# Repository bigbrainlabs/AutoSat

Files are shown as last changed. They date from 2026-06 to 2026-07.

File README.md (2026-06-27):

# AutoSat

Automatische Satelliten-Ausrichtung mit Echtzeit-Tracking für kleine Flachantennen/Schüsseln (35–40 cm) – hält den Satelliten auch während der Fahrt im Fokus. Für Boote, Wohnmobile, Caravans.

**Ziel:** DIY statt teure kommerzielle Systeme. Selbstgemacht ist wissen was drin ist und bezahlbar.

> Status: 🔧 Prototyp in Betrieb – Feinabstimmung läuft

---

## Konzept

Astra 19.2°E ist geostationär – steht fest am Himmel. Bewegt sich das Boot (dreht, schaukelt), muss die Schüssel nachgeführt werden – aktiv, auch während der Fahrt.

Die Plattform dreht sich auf einer Drehachse (Azimut), ein Servo kippt die Schüssel (Elevation). Ein IMU mit Kompass und Gyroskop misst die aktuelle Ausrichtung; die Firmware berechnet daraus den Fehler und korrigiert ihn.

**Tracking-Ansatz:** absolutes Azimut-Tracking über Kompassheading. Die Plattform wird einmalig nach Süden ausgerichtet (Kalibrierung), danach kennt das System jederzeit die absolute Schüsselrichtung:

```
Schüsselrichtung = Kompass-Heading + Motorposition + Montageoffset
Fehler = Ziel-Azimut − Schüsselrichtung
```

Elevation wird einmalig kalibriert (Servo-Winkel bei Satellitensignal gespeichert) und im Tracking per IMU-Achse für Boots-Neigung korrigiert.

---

## Hardware (aktueller Aufbau)

| # | Komponente | Funktion | Link |
|---|---|---|---|
| 1 | ESP32-C3 SuperMini | Steuerung, WiFi Access Point | [Amazon](https://amzn.to/4w9G6VN) |
| 2 | GY-91 (MPU-6500 + BMP280) | Gyroskop + Beschleunigung (Pitch/Roll/Yaw) | [Amazon](https://amzn.to/4wfitv6) |
| 3 | GY-271 (HMC5883L) | Magnetometer / Kompass | [Amazon](https://amzn.to/3QKusSe) |
| 4 | TMC2209 Schrittmotortreiber | Azimut-Motor, UART-Ansteuerung, StealthChop | [Amazon](https://amzn.to/3SqNw8E) |
| 5 | NEMA17 Schrittmotor | Azimut-Antrieb, Zahnradübersetzung 2:1 | [Amazon](https://amzn.to/4g7nUHM) |
| 6 | MG996R Servo | Elevation-Antrieb | [Amazon](https://amzn.to/4w8z7MJ) |
| 7 | GT2-Riemen + Umlenkrolle | Kraftübertragung Azimut-Antrieb | [Amazon](https://amzn.to/4oPDdqM) |
| 9 | Drehlager für Plattform | Zentrale Drehachse | [Amazon](https://amzn.to/4oMyjL0) |
| 10 | Schleifring 6-polig | Strom- & Signalübertragung über die Drehachse (verhindert Kabelwicklung) | [Amazon](https://amzn.to/4eMYXz2) |
| 11 | DC-DC Konverter 12V → 5V | Bordnetz-Versorgung für Servo und ESP32 | [Amazon](https://amzn.to/4oSf8zE) |

> Spannungsversorgung und Kleinmaterial (Kabel, Stecker, Dupont) nach eigenem Bedarf.

### Pin-Belegung

| Pin | Funktion |
|---|---|
| GPIO2 | STEP (TMC2209) |
| GPIO4 | DIR (hardwärts verkabelt, ungenutzt – Richtung via UART) |
| GPIO5 | Servo (MG996R, PWM) |
| GPIO6 | I2C SDA (MPU-6500, HMC5883L) |
| GPIO7 | I2C SCL |
| GPIO8 | TMC2209 UART TX (= LED-Pin, flackert bei Richtungswechsel) |
| GND | TMC2209 ENABLE (fest LOW = immer aktiv) |

### Wichtige Hardware-Eigenheiten

- **ESP32-C3 ist Single-Core (RISC-V):** `noInterrupts()` blockiert auch den WiFi-Stack. Gelöst durch minimale Interrupt-Blackouts (nur Adresse 3 ansprechen, ~8 ms) + `yield()` danach.
- **TMC2209 UART-Adresse = 3:** Bei 1/16-Mikroschritt sind MS1=HIGH, MS2=HIGH → UART-Adresse = 2·MS2+MS1 = 3. Adresse 0 wäre falsch.
- **NEMA17 Resonanzzone:** 80–300 Vollschritte/s → bei 16× Mikroschritt Mindest-Delay 800 µs/Schritt (= 39 Vollschritte/s).
- **Richtungssteuerung per UART:** DIR-Pin wird vom IC ignoriert; Richtung läuft über GCONF.shaft-Bit (Register 0x00).

---

## Software-Architektur

### Firmware (`firmware/firmware.ino` + `firmware/webportal.h`)

**IMU-Filter:**
- Pitch/Roll: Komplementärfilter, α=0.98 (Gyro + Beschleunigungssensor)
- Yaw/Heading: dynamisches α – bei Drehung 0.97 (Gyro dominiert), bei Stillstand 0.85 (Kompass zieht Drift heraus)
- Tilt-kompensiertes Magnetometer-Heading (Pitch/Roll-Korrektur)

**Azimut-Tracking:**
- Absolut: `dishAz = heading_yaw + currentSteps/STEPS_PER_DEGREE + azMountOffset`
- `azMountOffset` wird einmalig bei Süd-Kalibrierung gesetzt und in NVM gespeichert
- Soft-Limits: ±180° × STEPS_PER_DEGREE (nach Kalibrierung dynamisch gesetzt)

**Elevation-Tracking:**
- Referenz-Servo-Winkel (`servoCalAngle`) einmalig kalibriert und in NVM gespeichert
- Korrektur per wählbarer IMU-Achse: +Pitch / +Roll / −Pitch / −Roll (über Portal einstellbar)
- Rampe: manuell 60 ms/° (~16°/s), Live-Tracking 12 ms/° (~83°/s)
- Servo nach Neustart deaktiviert – muss im Portal explizit freigegeben werden

**Wichtige Parameter:**

| Parameter | Wert | Bedeutung |
|---|---|---|
| STEPS_PER_DEGREE | 17,78 | 200 Schritte/U × 16× Mikro × 2:1 Übersetzung |
| STEP_DELAY_TRACK | 300 µs | Tracking-Schrittgeschwindigkeit |
| STEP_MAN_MIN | 800 µs | Minimaler manueller Delay (Resonanz vermeiden) |
| TMC IRUN | 25 % (IRUN=8) | Motorstrom Fahren |
| TMC IHOLD | 6 % (IHOLD=2) | Motorstrom Halten |

---

## Web-Portal

Der ESP32-C3 öffnet einen WiFi Access Point (`AutoSat`). Portal unter `192.168.4.1`.

**Tabs:**

| Tab | Inhalt |
|---|---|
| Status | Tracking starten/stoppen, Süd-Referenz setzen, Azimut-Kalibrierung |
| Elevation | Servo freigeben, manuell positionieren, MIN/MAX setzen, kalibrieren, Achse wählen |
| GPS/Sat | Koordinaten, Satelliten-Längengrad, Azimut/Elevation-Anzeige |
| Motor | Manuelle Azimut-Schritte, Motor-Test, Step-Limits setzen |
| WiFi | WLAN-Client konfigurieren (optional, für MQTT/Internet) |
| Debug | Live-Rohdaten IMU, Heading, Fehlerwinkel, Loop-Hz |

---

## Kalibrierung (Erstinbetriebnahme)

### 1. Azimut – Süd-Referenz setzen

1. Plattform physisch nach Süden drehen (Kompass-App oder Markierung)
2. Portal → Status → **„Süd-Referenz setzen"**
3. Firmware setzt: `currentSteps = 0`, Soft-Limits ±180°, `azMountOffset` aus aktuellem Kompasswert
4. Einmalig – wird in NVM gespeichert, gilt für alle Neustarts

### 2. Elevation – Servo kalibrieren

1. Portal → Elevation → **„Servo aktivieren"** (Servo fährt auf gespeicherte Position)
2. Servo manuell mit ±1°/±10°-Buttons auf Satellitensignal ausrichten
3. Portal → Elevation → **„Kalibrieren & speichern"**
4. Dieser Servo-Winkel wird als Referenz gespeichert

### 3. Elevation-Korrekturachse wählen

1. Tracking starten
2. Boot seitlich kippen → Schüssel muss in die richtige Richtung nachkorrigieren
3. Falls falsch: Portal → Elevation → anderen Achsen-Button (+Pitch / +Roll / −Pitch / −Roll) probieren

### 4. Tracking starten

1. Portal → Status → **„Tracking starten"** (kalibriert Gyro-Offset für ~2,5 s)
2. System hält Astra 19.2°E automatisch im Fokus

---

## Ablauf nach jedem Neustart

1. ESP32 startet, WiFi-AP `AutoSat` verfügbar
2. Servo ist **deaktiviert** – keine automatische Bewegung
3. Portal öffnen → Elevation → **„Servo aktivieren"** → Servo fährt auf kalibrierten Winkel
4. Portal → Status → **„Tracking starten"**

Azimut-Motor startet sofort an der gespeicherten Step-Position aus dem letzten Betrieb (NVM).

---

## Repo-Struktur

```
AutoSat/
├── README.md
├── firmware/
│   ├── firmware.ino               ← Haupt-Firmware (IMU, Motor, Tracking, NVM)
│   └── webportal.h                ← Web-Portal (HTML/CSS/JS + HTTP-Handler)
├── docs/
│   ├── bedienung-webportal.md     ← Bedienung & Kalibrierung über das Web-Portal
│   └── schaltplan.md              ← Schaltplan & Verdrahtung aller Komponenten
└── 3D-Print-Parts/
    ├── Autosat-Elevation_Mount.stl  ← Halterung Elevation-Servo
    └── Nema17-Ground_Mount.stl      ← Grundhalterung NEMA17 Azimut-Motor
```

**Dokumentation:**
- [Bedienung & Kalibrierung über das Web-Portal](docs/bedienung-webportal.md)
- [Schaltplan & Verdrahtung](docs/schaltplan.md)

---

## NVM-Schlüssel (Preferences, Namespace "autosat")

| Schlüssel | Typ | Bedeutung |
|---|---|---|
| `steps` | Long | Letzte Motor-Position |
| `azMntOff` | Float | Azimut-Montageoffset (Süd-Kalibrierung) |
| `azMin` / `azMax` | Long | Azimut Soft-Limits in Steps |
| `srvCalAng` | Int | Kalibrierter Servo-Winkel (Elevation) |
| `servoMin` / `servoMax` | Int | Servo-Endpunkte |
| `elvAxis` | Int | Korrektur-Achse (0=+Pitch, 1=+Roll, 2=−Pitch, 3=−Roll) |
| `gpsLat` / `gpsLon` | Double | GPS-Koordinaten |
| `satLon` | Float | Satelliten-Längengrad (Default: 19.2) |
| `azOffset` | Float | Azimut-Offset für Satellitenberechnung |
| `azMountOffset` | Float | (identisch mit azMntOff, älterer Schlüssel) |

---

## Offene Punkte

- [ ] Genauigkeit bei längerem Betrieb auf dem Wasser testen
- [ ] Kompass-Kalibrierung (Hard/Soft-Iron) implementieren
- [ ] Achsen-Transformation (cos/sin) bei bekannter Board-Montage aktivieren
- [ ] MQTT-Integration (optional)
- [ ] Gehäuse / wetterfeste Montage

---

---

## Projekt unterstützen

Wer das Projekt gut findet – ich schreibe die Buch-Serie **„Logbuch ohne Pose"** über das Leben auf dem Boot, ehrlich und ungeschönt. In **Band 7** wird AutoSat eine Rolle spielen.

👉 [Logbuch ohne Pose – bei Amazon](https://amzn.to/4w6gBo9)

Mit dem Kauf eines Bandes oder der ganzen Serie unterstützt du die Weiterentwicklung direkt. Danke! ⚓

---

## Lizenz

Dieses Projekt steht unter der **GNU General Public License v3.0 (GPL-3.0)**.

Das bedeutet: Du kannst den Code frei verwenden, verändern und weitergeben – solange Ableitungen ebenfalls unter der GPL v3 veröffentlicht werden und die Quelle angegeben wird.

Weitere Details: [https://www.gnu.org/licenses/gpl-3.0.html](https://www.gnu.org/licenses/gpl-3.0.html)

---

*"~50 € DIY. ~3.000 € kommerziell. Der Rest ist Physik."* ⚓

🐾 Buster ist nach wie vor skeptisch.

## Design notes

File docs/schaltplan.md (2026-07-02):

# AutoSat – Schaltplan & Verdrahtung

> **Grafischer Schaltplan:** [Fritzing/autosat_v1.fzz](../Fritzing/autosat_v1.fzz)

## Systemübersicht

```
                        ┌──────────────────────────┐
                        │     ESP32-C3 SuperMini    │
                        │                          │
          3,3V ────────►│ 3V3              GPIO2   ├──── STEP ────────────► TMC2209
           GND ────────►│ GND              GPIO4   ├──── DIR  ────────────► TMC2209 (per UART übersteuert)
                        │                  GPIO5   ├──── PWM  ────────────► MG996R Servo (Signal)
                        │                  GPIO6   ├──── SDA  ─────┬──────► GY-91 (MPU-6500)
                        │                  GPIO7   ├──── SCL  ─────┴──────► GY-271 (HMC5883L)
                        │                  GPIO8   ├──── UART TX ─────────► TMC2209 PDN_UART
                        └──────────────────────────┘
```

---

## Stromversorgung

```
Bordnetz 12 V
    │
    ├──► TMC2209  VM  (12 V Motorspannung)
    │
    └──► DC-DC Konverter 12 V → 5 V
              │
              ├──► MG996R Servo  VCC (5 V)
              │
              └──► ESP32-C3  5V-Pin (nicht USB – direkt auf 5V-Rail)
                        │
                        └── 3,3 V intern (für GY-91, GY-271, TMC2209 VIO)
```

> Den ESP32-C3 am 5V-Pin (nicht USB-C) anschließen, wenn der DC-DC Konverter die Versorgung übernimmt. Nie gleichzeitig USB und externen 5V anlegen.

---

## ESP32-C3 SuperMini – Pin-Belegung

| GPIO | Funktion | Ziel |
|---|---|---|
| GPIO2 | STEP (Digital Out) | TMC2209 STEP |
| GPIO4 | DIR (Digital Out, ungenutzt) | TMC2209 DIR |
| GPIO5 | PWM (Servo) | MG996R Signal-Kabel |
| GPIO6 | I2C SDA | GY-91 SDA + GY-271 SDA |
| GPIO7 | I2C SCL | GY-91 SCL + GY-271 SCL |
| GPIO8 | UART TX (Software Serial) | TMC2209 PDN_UART |
| GND | Masse | Alle Komponenten |
| 3V3 | 3,3-V-Ausgang | GY-91 VCC, GY-271 VCC, TMC2209 VIO |

---

## TMC2209 Schrittmotortreiber

```
ESP32-C3 GPIO2  ──────────────────────► STEP
ESP32-C3 GPIO4  ──────────────────────► DIR
ESP32-C3 GPIO8  ──── 1 kΩ ────────────► PDN_UART  ◄──── 100 kΩ Pull-up ── 3,3 V
ESP32-C3 GND    ──────────────────────► EN   (fest LOW = immer aktiv)
ESP32-C3 3V3    ──────────────────────► VIO
Bordnetz 12 V   ──────────────────────► VM
GND             ──────────────────────► GND

MS1             ──────────────────────► 3,3 V   (HIGH)
MS2             ──────────────────────► 3,3 V   (HIGH)
                                       → UART-Adresse 3 (2×MS2 + MS1 = 2×1 + 1 = 3)

NEMA17 Spule A  ──────────────────────► 1A / 1B
NEMA17 Spule B  ──────────────────────► 2A / 2B
```

**PDN_UART-Beschaltung (Single-Wire UART):**

```
ESP32 GPIO8 ──┬── 1 kΩ ──► PDN_UART
              │
            (optional: 100 kΩ Pull-up nach 3,3 V direkt am PDN_UART-Pin)
```

> Richtungssteuerung läuft ausschließlich per UART (GCONF.shaft-Bit, Register 0x00). Der DIR-Pin wird vom IC ignoriert.

---

## GY-91 (MPU-6500 + BMP280) – Gyroskop & Beschleunigung

| GY-91 Pin | ESP32-C3 Pin |
|---|---|
| VCC | 3V3 |
| GND | GND |
| SDA | GPIO6 |
| SCL | GPIO7 |

> I2C-Adresse MPU-6500: **0x68** (AD0 auf GND)

---

## GY-271 (HMC5883L) – Magnetometer / Kompass

| GY-271 Pin | ESP32-C3 Pin |
|---|---|
| VCC | 3V3 |
| GND | GND |
| SDA | GPIO6 (gemeinsamer I2C-Bus mit GY-91) |
| SCL | GPIO7 (gemeinsamer I2C-Bus mit GY-91) |

> I2C-Adresse HMC5883L: **0x1E** (fest)

### I2C-Bus Pull-ups

Beide Sensoren hängen am selben I2C-Bus. Falls keine Pull-ups auf den Modulen vorhanden sind (GY-91 und GY-271 haben sie meist onboard):

```
SDA ──── 4,7 kΩ ──── 3,3 V
SCL ──── 4,7 kΩ ──── 3,3 V
```

---

## MG996R Servo – Elevation-Antrieb

| Servo-Kabel | Anschluss |
|---|---|
| Signal (Orange/Gelb) | ESP32-C3 GPIO5 |
| VCC (Rot) | DC-DC Konverter 5 V |
| GND (Braun/Schwarz) | GND (gemeinsam mit ESP32) |

> Der Servo sitzt auf der rotierenden Plattform – Signal, VCC und GND werden über den 6-poligen Schleifring in der Drehachse geführt.

---

## NEMA17 Schrittmotor – Azimut-Antrieb

Die vier Motorleitungen werden an den TMC2209 angeschlossen. Typische Farbbelegung (je nach Hersteller prüfen!):

| Motorleitung | TMC2209 Pin | Typische Farbe |
|---|---|---|
| Spule A+ | 1A | Schwarz |
| Spule A− | 1B | Grün |
| Spule B+ | 2A | Rot |
| Spule B− | 2B | Blau |

> Spulenpaare mit Multimeter messen: beide Enden einer Spule zeigen Widerstand (~1–5 Ω). Kreuzpaarung dreht den Motor rückwärts – einfach ein Spulenpaar umpolen.

---

## Häufige Fehler

- **GND nicht gemeinsam:** Alle Komponenten müssen auf dem selben GND-Potential liegen. Servo-GND unbedingt mit ESP32-GND verbinden, sonst fehlerhaftes PWM-Signal.
- **TMC2209 UART-Adresse falsch:** MS1 und MS2 müssen beide HIGH (3,3 V) sein → Adresse 3. Adresse 0 (beide LOW) führt zu keiner Kommunikation.
- **Magnetometer zu nah am Motor:** HMC5883L muss möglichst weit weg von NEMA17 und den Motorstromkabeln montiert sein – starke Störfelder verfälschen den Kompasswert.
- **Servo direkt an 3,3 V:** Führt zu Brownouts des ESP32. Immer externe 5-V-Versorgung (DC-DC Konverter) verwenden.

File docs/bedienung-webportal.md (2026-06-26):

# AutoSat – Bedienung & Kalibrierung über das Web-Portal

## Verbindung herstellen

1. ESP32-C3 einschalten (USB oder Bordstrom)
2. Mit dem WLAN-Netz **AutoSat** verbinden (kein Passwort)
3. Browser öffnen → `192.168.4.1`

---

## Tabs im Überblick

| Tab | Funktion |
|---|---|
| **Status** | Tracking starten/stoppen, Süd-Referenz setzen |
| **Elevation** | Servo steuern, Elevation kalibrieren, Korrekturachse wählen |
| **GPS/Sat** | GPS-Koordinaten eingeben, Satelliten-Längengrad festlegen |
| **Motor** | Manuelle Azimut-Schritte, Step-Limits setzen |
| **WiFi** | Optionaler WLAN-Client für MQTT/Internet |
| **Debug** | Live-Rohdaten: IMU, Heading, Fehlerwinkel, Loop-Hz |

---

## Erstinbetriebnahme (einmalig)

### Schritt 1 – GPS-Koordinaten eingeben

Tab **GPS/Sat** → eigene Breite/Länge eintragen → **Speichern**.  
Der Satellit (Standard: Astra 19.2°E) wird automatisch berechnet.

### Schritt 2 – Azimut-Südkalibrierung

1. Plattform physisch nach **Süden** drehen (Kompass-App oder Markierung am Gerät)
2. Tab **Status** → **„Süd-Referenz setzen"**
3. Das System setzt `currentSteps = 0`, berechnet den Montageoffset aus dem aktuellen Kompasswert und speichert alles dauerhaft im NVM

> Diese Kalibrierung gilt für alle Neustarts. Nur wiederholen, wenn die Plattform physisch umgebaut wurde.

### Schritt 3 – Elevation-Servo kalibrieren

1. Tab **Elevation** → **„Servo aktivieren"**  
   Der Servo fährt auf den zuletzt gespeicherten Winkel.
2. Mit **+1° / −1°** (Feinabstimmung) oder **+10° / −10°** (grob) auf Satellitensignal ausrichten  
   → Empfang prüfen am TV oder Receiver (maximale Signalstärke)
3. **„Kalibrieren & speichern"** – dieser Servo-Winkel ist jetzt die Referenz für den Tracking-Betrieb

### Schritt 4 – Korrekturachse wählen

1. Tab **Status** → **„Tracking starten"**
2. Boot seitlich kippen – die Schüssel muss aktiv gegensteuern
3. Falls sie in die falsche Richtung korrigiert:  
   Tab **Elevation** → anderen Achsen-Button wählen: **+Pitch / −Pitch / +Roll / −Roll**
4. Solange wechseln, bis die Korrektur stimmt

---

## Normaler Betrieb (nach jedem Neustart)

1. Mit WLAN **AutoSat** verbinden, Portal öffnen
2. Tab **Elevation** → **„Servo aktivieren"**  
   (Servo ist nach Neustart deaktiviert – Sicherheitsmaßnahme)
3. Tab **Status** → **„Tracking starten"**  
   Das System kalibriert den Gyro-Offset für ca. 2,5 Sekunden, dann läuft das Tracking automatisch

> Der Azimut-Motor startet sofort an der gespeicherten Step-Position aus dem letzten Betrieb.

---

## Tracking manuell stoppen

Tab **Status** → **„Tracking stoppen"**  
Servo und Motor bleiben in ihrer aktuellen Position, reagieren aber nicht mehr auf Bewegungen.

---

## Motor manuell bewegen (Tab: Motor)

- **Schritte +/−**: Azimut manuell in Schritten verfahren (zum Testen oder Ausrichten)
- **Step-Limits setzen**: Soft-Limits für den Azimut-Bereich definieren (verhindert Kabelwicklung)
- **Motor-Test**: Kurzer Testlauf, um Motorstrom und Verbindung zu prüfen

---

## Debug-Tab – was bedeutet was?

| Wert | Bedeutung |
|---|---|
| **Heading** | Berechnetes Kompass-Heading (tilt-kompensiert), 0°=Nord |
| **Pitch / Roll** | Neigung des Boards in Grad |
| **dishAz** | Aktuelle berechnete Schüsselrichtung (absolut) |
| **Fehlerwinkel** | Differenz Ziel-Azimut − dishAz (was der Motor korrigieren muss) |
| **Loop-Hz** | Verarbeitungsgeschwindigkeit der Firmware-Hauptschleife |

---

## Häufige Probleme

**Tracking dreht in die falsche Richtung (Azimut)**  
→ Süd-Kalibrierung wiederholen. Plattform muss beim Setzen der Referenz exakt nach Süden zeigen.

**Elevation korrigiert falsch bei Schaukeln**  
→ Korrekturachse wechseln (Tab Elevation, +Pitch/−Pitch/+Roll/−Roll).

**Servo reagiert nicht**  
→ Servo nach jedem Neustart erst über „Servo aktivieren" freigeben.

**Kompass dreht beim Betrieb der Motoren**  
→ Magnetometer (GY-271) so weit wie möglich von Schrittmotor und Stromkabeln entfernt montieren.

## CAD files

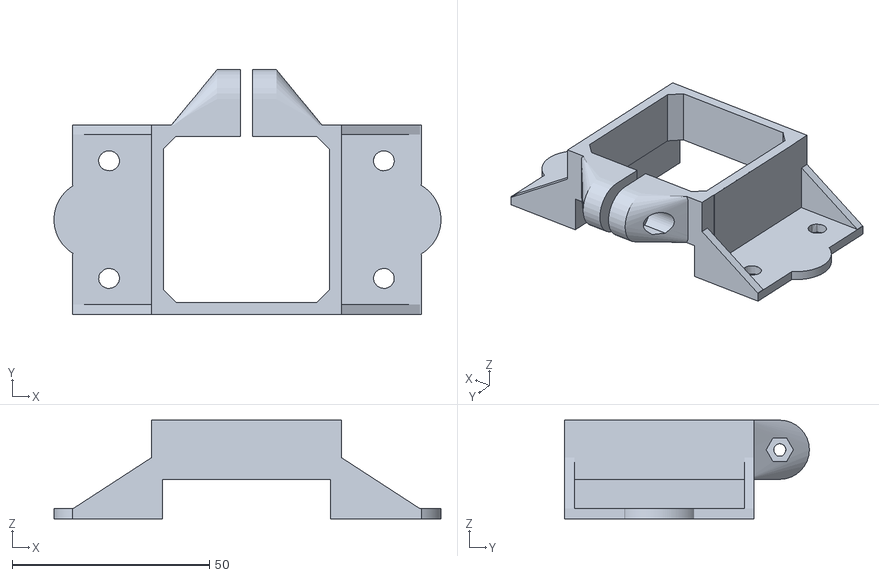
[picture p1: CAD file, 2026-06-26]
3D-Print-Parts/Nema17-Ground_Mount.stl
98.0 x 62.0 x 25.0

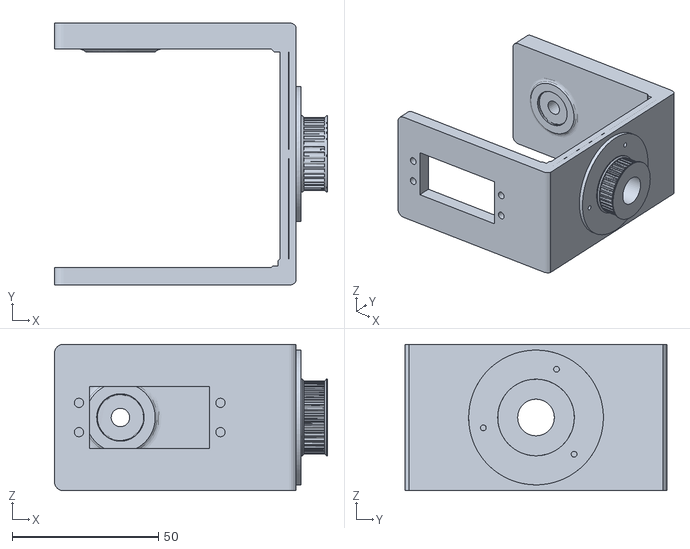
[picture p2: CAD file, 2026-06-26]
3D-Print-Parts/Autosat-Elevation_Mount.stl
93.2 x 89.6 x 50.0

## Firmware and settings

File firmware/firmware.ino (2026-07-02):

/*
 * AutoSat – Automatische Satelliten-Ausrichtung
 * Band 7 "Logbuch ohne Pose" – bigbrainlabs
 *
 * Hardware:
 *   - ESP32-C3 SuperMini
 *   - GY-91 (MPU-6500) an I2C (SDA=GPIO6, SCL=GPIO7)
 *   - A4988 Motortreiber (STEP=GPIO2, DIR=GPIO4, EN=GND fest)
 *   - MG996R Servo Elevation (GPIO5)
 *   - NEMA17 Azimut, 1/16 Microstepping, 20Z Motor / 40Z Plattform
 *
 * GPS: hardcoded (Leipzig) – später via MQTT/Webinterface
 * Satellit: Astra 19.2° Ost
 * Webportal: WLAN "AutoSat" / PW "autosat1" → http://192.168.4.1
 */

#include <Wire.h>
#include <ESP32Servo.h>
#include <math.h>

// ═══════════════════════════════════════════════
// PINS
// ═══════════════════════════════════════════════
#define STEP_PIN     2
#define DIR_PIN      4
// ENABLE dauerhaft auf GND gebrückt am TMC2209
#define SERVO_PIN    5
#define I2C_SDA      6
#define I2C_SCL      7

// ═══════════════════════════════════════════════
// MOTORKONFIGURATION
// ═══════════════════════════════════════════════
#define STEPS_PER_REV     200
#define MICROSTEPPING     16
#define GEAR_RATIO        2.0
#define STEPS_PER_DEGREE  (STEPS_PER_REV * MICROSTEPPING * GEAR_RATIO / 360.0)

#define STEP_DELAY_TRACK  300    // µs für Tracking (kleine Korrekturen)
#define STEP_MAN_MIN      800    // µs – unterhalb NEMA17 Resonanz (~39 Vollschr/s)
#define STEP_MAN_MAX     3000    // µs Anlauf/Auslauf
#define STEP_DELAY_US     STEP_DELAY_TRACK
#define MAX_ROTATIONS     1.5
#define YAW_SIGN          (+1)

// Magnetische Deklination Leipzig ≈ 3.3° Ost → mag_heading - 3.3 = true heading
// Webportal GPS/Sat-Tab → Azimut-Offset für Feinkalibrierung
#define MAG_DECLINATION   3.3f

// Komplementärfilter Yaw: dynamisch – bei Drehung mehr Gyro, bei Stillstand mehr Kompass
#define ALPHA_YAW_MOVING  0.97f   // aktive Drehung: Gyro dominiert (kurzzeitig präzise)
#define ALPHA_YAW_STILL   0.85f   // Stillstand: Kompass zieht Gyro-Drift heraus
#define GZ_MOVING_THR     3.0f    // °/s – ab hier gilt "Drehung erkannt"

// webportal.h hier einbinden: alle #defines sichtbar, Typen (WebServer etc.) verfügbar
#include "webportal.h"

// ═══════════════════════════════════════════════
// GPS + SATELLIT (Defaults, überschreibbar via Webportal)
// ═══════════════════════════════════════════════
double gps_lat = 51.3397;
double gps_lon = 12.3731;
double sat_lon = 19.2;
float  az_offset = 0.0;

// ═══════════════════════════════════════════════
// MPU REGISTER
// ═══════════════════════════════════════════════
#define MPU_ADDR     0x68
#define AK8963_ADDR  0x0C
#define PWR_MGMT_1   0x6B
#define ACCEL_XOUT_H 0x3B
#define INT_PIN_CFG  0x37
#define USER_CTRL    0x6A

// ═══════════════════════════════════════════════
// QMC5883L REGISTER (I2C 0x0D)
// ═══════════════════════════════════════════════
#define QMC_ADDR     0x0D
#define QMC_DATA     0x00
#define QMC_STATUS   0x06
#define QMC_CTRL1    0x09
#define QMC_CTRL2    0x0A
#define QMC_RESET    0x0B

// ═══════════════════════════════════════════════
// HMC5883L REGISTER (GY-271, I2C 0x1E)
// ═══════════════════════════════════════════════
#define HMC_ADDR     0x1E
#define HMC_CRA      0x00   // Config A: samples avg, data rate
#define HMC_CRB      0x01   // Config B: gain
#define HMC_MODE     0x02   // Mode register
#define HMC_DATA     0x03   // X_MSB, X_LSB, Z_MSB, Z_LSB, Y_MSB, Y_LSB

// ═══════════════════════════════════════════════
// DATENSTRUKTUREN
// ═══════════════════════════════════════════════
struct SensorData {
  float ax, ay, az;
  float gx, gy, gz;
  float mx, my, mz;
};

// ═══════════════════════════════════════════════
// GLOBALE VARIABLEN
// ═══════════════════════════════════════════════
Servo        elevationServo;
WebServer    server(80);
DNSServer    dnsServer;
Preferences  prefs;

long  currentSteps  = 0;
float pitch         = 0.0;
float roll          = 0.0;
float heading_yaw   = 0.0;
float gz_offset     = 0.0;

unsigned long lastTime      = 0;
unsigned long lastMotorTime = 0;
const float   ALPHA         = 0.98;

float targetAzimuth   = 0.0;
float targetElevation = 0.0;
bool  ak8963_ok       = false;
bool  qmc_ok          = false;
bool  hmc_ok          = false;

// Servo-Kalibrierung (persistent, Defaults bis erstes Speichern)
int          servoMin         = 20;   // Sicherer Default – nie auf 0° fahren
int          servoMax         = 75;   // Sicherer Default – kein Vollausschlag
int          servoManualAngle = 20;
int          servoCalAngle    = 0;    // Kalibrierter Winkel (0 = noch nicht kalibriert)
// Elevationskorrektur-Achse: 0=+Pitch  1=+Roll  2=-Pitch  3=-Roll
int          elevAxisMode    = 0;
int          servoTarget      = 20;   // Zielwinkel für langsame Rampe
int          servoActual      = 20;   // Tatsächlich geschriebener Winkel
bool         servoEnabled     = false; // Servo erst nach explizitem Aktivieren im Portal bewegen
bool         servoInitDone    = false; // true sobald Servo erstmals Ziel erreicht (danach Tracking-Speed)
bool         manualControl    = false;
unsigned long lastServoCmd    = 0;
unsigned long lastServoStep   = 0;    // Zeitstempel letzter Rampen-Schritt

// Motorposition + Servo-Position persistent
long         lastSavedSteps   = 0;
int          servoLastPos     = 0;    // Letzte bekannte Servo-Position (aus NVM)
bool         positionDirty    = false;

// WLAN-Credentials (persistent)
char         wlan_ssid[64]    = "";
char         wlan_pass[64]    = "";

// Debug-Daten (letzte Sensor-Messung, für Webportal)
float dbg_ax=0, dbg_ay=0, dbg_az=0;
float dbg_gx=0, dbg_gy=0, dbg_gz=0;
float dbg_mx=0, dbg_my=0, dbg_mz=0;
float dbg_gz_net=0;
bool  dbg_dir=false;
float loopHz=0;

// Tracking
bool  trackingEnabled = false;
float azMountOffset   = 0.0f;   // Montageoffset: Kompassnord→Schüssel bei steps=0

// Azimut-Softlimits (Steps), kalibrierbar über Webportal
// Default = voller mechanischer Bereich (MAX_ROTATIONS)
long azStepMin = -(long)(1.5f * 200 * 16 * 2.0f);   // -9600
long azStepMax =  (long)(1.5f * 200 * 16 * 2.0f);   // +9600

// ── Stufe 1: Motor-Flag + Vibrationserkennung ────────────────────────────
bool    motorRunning      = false;
bool    vibrationDetected = false;
bool    compassFrozen     = false;
float   accelMagBuf[10]   = {};
uint8_t accelBufIdx       = 0;

// ── Stufe 2: Kompass als separates Heading / Drift-Anker ─────────────────
float   compassHeading  = 0.0f;
float   compassBuf[40]  = {};
uint8_t compassBufIdx2  = 0;
bool    compassBufFull  = false;
bool    compassStable   = false;
unsigned long stillnessStart = 0;

// ═══════════════════════════════════════════════
// MPU INIT
// ═══════════════════════════════════════════════
void mpuInit() {
  Wire.beginTransmission(MPU_ADDR);
  Wire.write(0x75);
  Wire.endTransmission(false);
  Wire.requestFrom(MPU_ADDR, 1, true);
  byte id = Wire.read();
  Serial.print("MPU WHO_AM_I: 0x"); Serial.println(id, HEX);

  Wire.beginTransmission(MPU_ADDR);
  Wire.write(PWR_MGMT_1);
  Wire.write(0x00);
  Wire.endTransmission();
  delay(100);

  Wire.beginTransmission(MPU_ADDR);
  Wire.write(USER_CTRL);
  Wire.write(0x00);
  Wire.endTransmission();
  delay(10);

  Wire.beginTransmission(MPU_ADDR);
  Wire.write(INT_PIN_CFG);
  Wire.write(0x02);
  Wire.endTransmission();
  delay(10);

  Wire.beginTransmission(AK8963_ADDR);
  Wire.write(0x0A);
  Wire.write(0x00);
  Wire.endTransmission();
  delay(10);
  Wire.beginTransmission(AK8963_ADDR);
  Wire.write(0x0A);
  Wire.write(0x16);
  ak8963_ok = (Wire.endTransmission() == 0);
  delay(50);

  Serial.print("AK8963: ");
  Serial.println(ak8963_ok ? "OK" : "nicht gefunden");
}

// ═══════════════════════════════════════════════
// QMC5883L INIT
// ═══════════════════════════════════════════════
void qmcInit() {
  // Chip-ID prüfen
  Wire.beginTransmission(QMC_ADDR);
  Wire.write(0x0D);
  Wire.endTransmission(false);
  Wire.requestFrom(QMC_ADDR, 1, true);
  byte id = Wire.read();
  Serial.printf("QMC5883L Chip-ID: 0x%02X (erwartet 0xFF)\n", id);

  // SET/RESET period
  Wire.beginTransmission(QMC_ADDR);
  Wire.write(QMC_RESET);
  Wire.write(0x01);
  Wire.endTransmission();
  delay(10);

  // CTRL1: OSR=512, Range=8G, ODR=200Hz, Modus=Continuous
  // 0b00011101 = 0x1D
  Wire.beginTransmission(QMC_ADDR);
  Wire.write(QMC_CTRL1);
  Wire.write(0x1D);
  qmc_ok = (Wire.endTransmission() == 0);
  delay(10);

  Serial.print("QMC5883L: ");
  Serial.println(qmc_ok ? "OK" : "nicht gefunden");
}

// ═══════════════════════════════════════════════
// HMC5883L INIT
// ═══════════════════════════════════════════════
void hmc5883lInit() {
  Wire.beginTransmission(HMC_ADDR);
  Wire.write(HMC_CRA);
  Wire.write(0x70);  // 8 samples avg, 15 Hz, normal measurement
  Wire.endTransmission();
  delay(10);
  Wire.beginTransmission(HMC_ADDR);
  Wire.write(HMC_CRB);
  Wire.write(0x20);  // Gain 1090 LSB/Gauss (±1.3 Ga)
  Wire.endTransmission();
  delay(10);
  Wire.beginTransmission(HMC_ADDR);
  Wire.write(HMC_MODE);
  Wire.write(0x00);  // Continuous measurement mode
  hmc_ok = (Wire.endTransmission() == 0);
  delay(10);
  Serial.print("HMC5883L: ");
  Serial.println(hmc_ok ? "OK" : "nicht gefunden");
}

// ═══════════════════════════════════════════════
// MPU LESEN
// ═══════════════════════════════════════════════
SensorData readMPU() {
  SensorData data;

  Wire.beginTransmission(MPU_ADDR);
  Wire.write(ACCEL_XOUT_H);
  Wire.endTransmission(false);
  Wire.requestFrom(MPU_ADDR, 14, true);

  int16_t ax = (Wire.read() << 8) | Wire.read();
  int16_t ay = (Wire.read() << 8) | Wire.read();
  int16_t az = (Wire.read() << 8) | Wire.read();
  Wire.read(); Wire.read();
  int16_t gx = (Wire.read() << 8) | Wire.read();
  int16_t gy = (Wire.read() << 8) | Wire.read();
  int16_t gz = (Wire.read() << 8) | Wire.read();

  data.ax = ax / 16384.0;
  data.ay = ay / 16384.0;
  data.az = az / 16384.0;
  data.gx = gx / 131.0;
  data.gy = gy / 131.0;
  data.gz = gz / 131.0;

  data.mx = data.my = data.mz = 0.0f;

  if (qmc_ok) {
    // QMC5883L: Status prüfen, dann 6 Bytes lesen (little-endian)
    Wire.beginTransmission(QMC_ADDR);
    Wire.write(QMC_STATUS);
    Wire.endTransmission(false);
    Wire.requestFrom(QMC_ADDR, 1, true);
    byte st = Wire.read();
    if (st & 0x01) {
      Wire.beginTransmission(QMC_ADDR);
      Wire.write(QMC_DATA);
      Wire.endTransmission(false);
      if (Wire.requestFrom(QMC_ADDR, 6, true) == 6) {
        int16_t mx = (int16_t)(Wire.read() | (Wire.read() << 8));
        int16_t my = (int16_t)(Wire.read() | (Wire.read() << 8));
        int16_t mz = (int16_t)(Wire.read() | (Wire.read() << 8));
        data.mx = (float)mx;
        data.my = (float)my;
        data.mz = (float)mz;
      }
    }
  } else if (hmc_ok) {
    // HMC5883L: Reihenfolge X, Z, Y (nicht X, Y, Z!)
    Wire.beginTransmission(HMC_ADDR);
    Wire.write(HMC_DATA);
    Wire.endTransmission(false);
    if (Wire.requestFrom((uint8_t)HMC_ADDR, (uint8_t)6, (uint8_t)true) == 6) {
      int16_t mx = (int16_t)((Wire.read() << 8) | Wire.read());
      int16_t mz = (int16_t)((Wire.read() << 8) | Wire.read());
      int16_t my = (int16_t)((Wire.read() << 8) | Wire.read());
      data.mx = mx * 0.092f;  // 1090 LSB/Gauss → µT
      data.my = my * 0.092f;
      data.mz = mz * 0.092f;
    }
  } else if (ak8963_ok) {
    Wire.beginTransmission(AK8963_ADDR);
    Wire.write(0x02);
    Wire.endTransmission(false);
    if (Wire.requestFrom((uint8_t)AK8963_ADDR, (uint8_t)8, (uint8_t)true) == 8) {
      byte st1 = Wire.read();
      int16_t mx = (int16_t)(Wire.read() | (Wire.read() << 8));
      int16_t my = (int16_t)(Wire.read() | (Wire.read() << 8));
      int16_t mz = (int16_t)(Wire.read() | (Wire.read() << 8));
      Wire.read();
      if (st1 & 0x01) {
        data.mx = mx * 0.15f;
        data.my = my * 0.15f;
        data.mz = mz * 0.15f;
      }
    }
  }

  return data;
}

// ═══════════════════════════════════════════════
// KOMPLEMENTÄRFILTER (Pitch / Roll / Yaw)
// ═══════════════════════════════════════════════
void updateIMU(SensorData &d) {
  unsigned long now = millis();
  float dt = (now - lastTime) / 1000.0f;
  lastTime = now;

  // Pitch / Roll: Komplementärfilter aus Gyro + Beschleunigungssensor
  float accelPitch = atan2f(d.ay, d.az) * 180.0f / M_PI;
  float accelRoll  = atan2f(-d.ax, d.az) * 180.0f / M_PI;
  pitch = ALPHA * (pitch + d.gx * dt) + (1.0f - ALPHA) * accelPitch;
  roll  = ALPHA * (roll  + d.gy * dt) + (1.0f - ALPHA) * accelRoll;

  // Gyro-Heading (kurzfristig)
  float gz_net = d.gz - gz_offset;
  float gyro_hdg = heading_yaw;
  if (fabsf(gz_net) > 1.0f) {
    gyro_hdg += YAW_SIGN * gz_net * dt;
    if (gyro_hdg >= 360.0f) gyro_hdg -= 360.0f;
    if (gyro_hdg <    0.0f) gyro_hdg += 360.0f;
  }


  // Stufe 2: heading_yaw = rein Gyro; Kompass nur als Drift-Anker
  heading_yaw   = gyro_hdg;
  compassFrozen = motorRunning || vibrationDetected;

  bool hasCompass = (ak8963_ok || qmc_ok || hmc_ok) &&
                    (d.mx != 0.0f || d.my != 0.0f || d.mz != 0.0f);
  if (hasCompass) {
    // Tilt-kompensiertes Magnetometer-Heading (identische Rechnung wie zuvor)
    float cosR = cosf(roll  * M_PI / 180.0f);
    float sinR = sinf(roll  * M_PI / 180.0f);
    float cosP = cosf(pitch * M_PI / 180.0f);
    float sinP = sinf(pitch * M_PI / 180.0f);
    float Xh = d.mx * cosP + d.mz * sinP;
    float Yh = d.mx * sinR * sinP + d.my * cosR - d.mz * sinR * cosP;
    float ch = atan2f(-Yh, Xh) * 180.0f / M_PI;
    if (ch < 0.0f) ch += 360.0f;
    ch -= MAG_DECLINATION;
    if (ch < 0.0f) ch += 360.0f;
    compassHeading = ch;

    // Stabilitätspuffer: Standardabweichung über ~2s
    compassBuf[compassBufIdx2] = ch;
    compassBufIdx2 = (compassBufIdx2 + 1) % 40;
    if (compassBufIdx2 == 0) compassBufFull = true;
    if (compassBufFull) {
      float mean = 0;
      for (int i = 0; i < 40; i++) mean += compassBuf[i];
      mean /= 40.0f;
      float var = 0;
      for (int i = 0; i < 40; i++) {
        float ang_diff = compassBuf[i] - mean;
        while (ang_diff >  180.0f) ang_diff -= 360.0f;
        while (ang_diff < -180.0f) ang_diff += 360.0f;
        var += ang_diff * ang_diff;
      }
      compassStable = sqrtf(var / 40.0f) < 2.0f;
    }

    // Drift-Korrektur nur im gesicherten Stillstand (>5s, kein Motor, keine Vibration, Kompass stabil)
    if (!motorRunning && !vibrationDetected && compassStable) {
      if (stillnessStart == 0) stillnessStart = millis();
      if (millis() - stillnessStart > 5000) {
        float drift = compassHeading - heading_yaw;
        while (drift >  180.0f) drift -= 360.0f;
        while (drift < -180.0f) drift += 360.0f;
        heading_yaw += drift * 0.001f * dt;
        if (heading_yaw >= 360.0f) heading_yaw -= 360.0f;
        if (heading_yaw <    0.0f) heading_yaw += 360.0f;
      }
    } else {
      stillnessStart = 0;
    }
  }
}

// ═══════════════════════════════════════════════
// SATELLITENBERECHNUNG
// ═══════════════════════════════════════════════
void calcSatPosition(double lat, double lon, double satLon,
                     float &azimuth, float &elevation) {
  const double RE = 6371.0;
  const double RS = 42164.0;

  double latRad  = lat * M_PI / 180.0;
  double lonDiff = (satLon - lon) * M_PI / 180.0;

  double cosEl = cos(latRad) * cos(lonDiff);
  elevation = atan((cosEl - RE / RS) / sqrt(1.0 - cosEl * cosEl)) * 180.0 / M_PI;

  double az = atan2(sin(lonDiff), -sin(latRad) * cos(lonDiff));
  azimuth = az * 180.0 / M_PI;
  if (azimuth < 0) azimuth += 360.0;
}

// ═══════════════════════════════════════════════
// TMC2209 UART KONFIGURATION – Software-Bit-Bang (GPIO8 / PDN_UART)
// ═══════════════════════════════════════════════
#define TMC_UART_TX   8
#define TMC_BIT_US  104   // 9600 Baud → 104µs pro Bit

static uint8_t tmcCRC(uint8_t *buf, uint8_t n) {
  uint8_t crc = 0;
  for (uint8_t i = 0; i < n; i++) {
    uint8_t b = buf[i];
    for (uint8_t j = 0; j < 8; j++) {
      if ((crc >> 7) ^ (b & 1)) crc = (crc << 1) ^ 0x07;
      else crc <<= 1;
      b >>= 1;
    }
  }
  return crc;
}

static void tmcSendByte(uint8_t byte) {
  noInterrupts();                           // Bit-Timing sichern
  digitalWrite(TMC_UART_TX, LOW);          // Start-Bit
  delayMicroseconds(TMC_BIT_US);
  for (int i = 0; i < 8; i++) {
    digitalWrite(TMC_UART_TX, (byte >> i) & 1);
    delayMicroseconds(TMC_BIT_US);
  }
  digitalWrite(TMC_UART_TX, HIGH);         // Stop-Bit
  interrupts();
  delayMicroseconds(TMC_BIT_US);           // Stop-Bit-Dauer mit Interrupts
}

static void tmcWrite(uint8_t addr, uint8_t reg, uint32_t val) {
  uint8_t buf[8] = {
    0x05, addr, (uint8_t)(reg | 0x80),
    (uint8_t)(val >> 24), (uint8_t)(val >> 16),
    (uint8_t)(val >>  8), (uint8_t)(val), 0
  };
  buf[7] = tmcCRC(buf, 7);
  for (int i = 0; i < 8; i++) tmcSendByte(buf[i]);
  delayMicroseconds(200);
}

static void tmcWriteAll(uint8_t reg, uint32_t val) {
  // Adresse 3 = MS1=HIGH/MS2=HIGH = 1/16 Mikroschritt (bestätigt)
  // Nur eine Adresse → ~8ms Interrupt-Blackout statt 32ms
  tmcWrite(3, reg, val);
  yield();  // WiFi-Stack nach dem Send verarbeiten
}

static bool tmcCurDir = true;

void tmcSetDir(bool dir) {
  if (dir == tmcCurDir) return;
  tmcCurDir = dir;
  // GCONF: StealthChop, shaft-Bit invertiert (Hardware-Polung)
  tmcWriteAll(0x00, dir ? 0x00000008 : 0x00000000);
}

void tmcInit() {
  pinMode(TMC_UART_TX, OUTPUT);
  digitalWrite(TMC_UART_TX, HIGH);  // UART Idle = HIGH
  delay(10);
  tmcCurDir = false;
  // GCONF: shaft=0, StealthChop (entspricht dir=false nach Invertierung)
  tmcWriteAll(0x00, 0x00000000);
  // IHOLD_IRUN: IRUN=8 (25%), IHOLD=2 (6%), IHOLDDELAY=10
  // Für Satellitentracker mehr als ausreichend – minimale Wärmeentwicklung
  tmcWriteAll(0x10, 0x000A0802);
  delay(5);
  Serial.println("TMC2209: SoftUART init OK (StealthChop, IRUN=50%)");
}

// ═══════════════════════════════════════════════
// MOTOR
// ═══════════════════════════════════════════════
void stepMotor(bool dir, unsigned int stepDelay = STEP_DELAY_TRACK) {
  tmcSetDir(dir);               // Richtung per UART (shaft-Bit)
  digitalWrite(STEP_PIN, HIGH);
  delayMicroseconds(stepDelay);
  digitalWrite(STEP_PIN, LOW);
  delayMicroseconds(stepDelay);
  currentSteps  += dir ? 1 : -1;
  lastMotorTime  = millis();
  motorRunning   = true;
  positionDirty  = true;
  dbg_dir        = dir;
}

// Ramped stepping: langsam anlaufen, schnell fahren, langsam stoppen.
// Vermeidet Riemensprung (langsam) UND NEMA17-Resonanz (schnelle Cruise-Speed).
void stepMotorManual(bool dir, int count) {
  int ramp = min(count / 3, 10);
  for (int i = 0; i < count; i++) {
    unsigned int d;
    if (i < ramp)
      d = (unsigned int)(STEP_MAN_MAX - (long)(STEP_MAN_MAX - STEP_MAN_MIN) * i / max(ramp, 1));
    else if (i >= count - ramp)
      d = (unsigned int)(STEP_MAN_MIN + (long)(STEP_MAN_MAX - STEP_MAN_MIN) * (i - (count - ramp)) / max(ramp, 1));
    else
      d = STEP_MAN_MIN;
    stepMotor(dir, d);
  }
}

// ═══════════════════════════════════════════════
// MOTOR-FLAG + VIBRATIONSERKENNUNG (Stufe 1)
// ═══════════════════════════════════════════════
void updateMotorFlag() {
  if (motorRunning && millis() - lastMotorTime > 500)
    motorRunning = false;
}

void updateVibration(SensorData &d) {
  float mag = sqrtf(d.ax*d.ax + d.ay*d.ay + d.az*d.az);
  accelMagBuf[accelBufIdx++ % 10] = mag;
  float mean = 0;
  for (int i = 0; i < 10; i++) mean += accelMagBuf[i];
  mean /= 10.0f;
  float var = 0;
  for (int i = 0; i < 10; i++) var += (accelMagBuf[i]-mean)*(accelMagBuf[i]-mean);
  vibrationDetected = sqrtf(var / 10.0f) > 0.05f;
}

// ═══════════════════════════════════════════════
// AZIMUT NACHFÜHREN
// ═══════════════════════════════════════════════
void recalcSat() {
  calcSatPosition(gps_lat, gps_lon, sat_lon, targetAzimuth, targetElevation);
  Serial.printf("Neuberechnung: Az=%.1f° El=%.1f°\n", targetAzimuth, targetElevation);
}
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
void loop() {
  servoRampTick();   // Servo langsam zum Ziel bewegen (20ms/°)
  processWebPortal();

  // Manual-Timeout: 30s ohne Web-Befehl → Tracking übernimmt wieder
  if (manualControl && (millis() - lastServoCmd > 30000)) {
    manualControl = false;
    Serial.println("Manuelle Servo-Kontrolle beendet – Tracking aktiv.");
  }

  // Motorposition speichern: 5s nach letzter Bewegung, nur wenn geändert
  if (positionDirty && (millis() - lastMotorTime > 5000)) {
    prefs.begin("autosat", false);
    prefs.putLong("steps", currentSteps);
    prefs.putInt ("srvPos", servoActual);
    prefs.end();
    lastSavedSteps = currentSteps;
    servoLastPos   = servoActual;
    positionDirty  = false;
  }

  updateMotorFlag();
  SensorData data = readMPU();
  updateVibration(data);
  updateIMU(data);
  if (trackingEnabled) {
    updateAzimuth(heading_yaw);
    updateElevation();
  }

  // Debug-Snapshot für Webportal
  dbg_ax = data.ax; dbg_ay = data.ay; dbg_az = data.az;
  dbg_gx = data.gx; dbg_gy = data.gy; dbg_gz = data.gz;
  dbg_mx = data.mx; dbg_my = data.my; dbg_mz = data.mz;
  dbg_gz_net = data.gz - gz_offset;

  // Loop-Frequenz messen
  static unsigned long hzTimer = 0;
  static int hzCount = 0;
  hzCount++;
  if (millis() - hzTimer >= 1000) {
    loopHz  = hzCount;
    hzCount = 0;
    hzTimer = millis();
  }

  static unsigned long lastPrint = 0;
  if (millis() - lastPrint > 500) {
    lastPrint = millis();
    float dish = heading_yaw + (float)currentSteps / STEPS_PER_DEGREE + azMountOffset;
    while (dish >= 360.0f) dish -= 360.0f;
    while (dish <    0.0f) dish += 360.0f;
    float err = targetAzimuth - dish;
    while (err >  180.0f) err -= 360.0f;
    while (err < -180.0f) err += 360.0f;
    Serial.printf("Hdg:%.1f° Cmp:%.1f° gz:%.2f  Err:%.1f°  Steps:%ld  Srv:%d°  Mag:%s%s%s\n",
      heading_yaw, compassHeading, data.gz - gz_offset, err, currentSteps,
      servoManualAngle,
      qmc_ok ? "QMC" : (hmc_ok ? "HMC" : (ak8963_ok ? "AK" : "OFF")),
      compassFrozen ? " [COMP-FRZ]" : (compassStable ? " [COMP-OK]" : ""),
      manualControl ? " [MANUELL]" : "");
  }
}

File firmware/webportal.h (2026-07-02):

#pragma once

void tmcSetDir(bool dir);   // definiert in firmware.ino
void servoMoveTo(int angle, bool tracking = false); // definiert in firmware.ino

#include <WiFi.h>
#include <WebServer.h>
#include <DNSServer.h>
#include <ESPmDNS.h>
#include <Preferences.h>
#include <ESP32Servo.h>

// ─── Globals defined in firmware.ino ──────────────────────────────────────
extern WebServer     server;
extern DNSServer     dnsServer;
extern Preferences   prefs;
extern Servo         elevationServo;
extern int           servoMin, servoMax, servoManualAngle;
extern int           servoCalAngle, servoTarget, servoActual;
extern int           elevAxisMode;
extern bool          servoEnabled, servoInitDone;
extern bool          manualControl;
extern unsigned long lastServoCmd, lastMotorTime;
extern long          currentSteps, azStepMin, azStepMax;
extern float         heading_yaw, pitch, roll, targetAzimuth, targetElevation;
extern float         gz_offset;
extern double        gps_lat, gps_lon, sat_lon;
extern float         az_offset;
extern char          wlan_ssid[64], wlan_pass[64];
extern bool          ak8963_ok, qmc_ok, hmc_ok, trackingEnabled;
extern float         azMountOffset;
extern float         dbg_ax, dbg_ay, dbg_az;
extern float         dbg_gx, dbg_gy, dbg_gz;
extern float         dbg_mx, dbg_my, dbg_mz;
extern float         dbg_gz_net, loopHz;
extern bool          dbg_dir;
extern bool          positionDirty;
extern bool          motorRunning, vibrationDetected, compassFrozen, compassStable;
extern float         compassHeading;
extern void          recalcSat();
extern void          calibrateGyroOffset();
extern void          stepMotorManual(bool dir, int count);

// ─── HTML ─────────────────────────────────────────────────────────────────
static const char PORTAL_HTML[] PROGMEM = R"rawliteral(
<!DOCTYPE html>
<html lang="de">
<head>
<meta charset="UTF-8">
<meta name="viewport" content="width=device-width,initial-scale=1">
<title>AutoSat</title>
<style>
*{box-sizing:border-box;margin:0;padding:0}
body{font-family:sans-serif;background:#1a1a2e;color:#eee;max-width:440px;margin:0 auto;padding:12px}
h2{color:#a0c4ff;text-align:center;padding:10px 0 14px}
.tabs{display:flex;gap:3px;margin-bottom:12px}
.tab{flex:1;padding:8px 2px;background:#16213e;border:none;color:#666;border-radius:8px;cursor:pointer;font-size:.75em}
.tab.on{background:#0f3460;color:#a0c4ff}
.box{background:#16213e;border-radius:12px;padding:14px;margin:10px 0}
.row{display:flex;justify-content:space-between;align-items:center;padding:5px 0;border-bottom:1px solid #222}
.row:last-child{border:none}
.lbl{color:#888;font-size:.88em}
.val{color:#a0c4ff;font-weight:bold}
.big{font-size:2em;color:#a0c4ff;font-weight:bold}
.center{text-align:center}
button{padding:11px 14px;margin:3px;border:none;border-radius:8px;cursor:pointer;color:#fff;font-size:.95em}
.bm{background:#334}.bmin{background:#8b0000}.bmax{background:#006400}
.bsave{background:#00408b;width:100%;padding:13px;font-size:1.05em;margin-top:8px}
.bwarn{background:#7a3800;width:100%;padding:13px;font-size:1.05em}
.bdis{background:#4a0000;width:100%;padding:11px;font-size:.95em;margin-top:6px}
.btrack-on {background:#006400;width:100%;padding:14px;font-size:1.1em;font-weight:bold}
.btrack-off{background:#8b0000;width:100%;padding:14px;font-size:1.1em;font-weight:bold}
.bsm{padding:9px 12px;font-size:.88em}
label{display:block;color:#888;font-size:.82em;margin:8px 0 2px}
input{background:#0f3460;color:#eee;border:1px solid #334;border-radius:6px;padding:8px;width:100%;font-size:.95em}
.pw-wrap{position:relative}.pw-wrap input{padding-right:44px}
.pw-eye{position:absolute;right:8px;top:50%;transform:translateY(-50%);background:none;border:none;color:#888;cursor:pointer;width:auto;padding:4px}
.msg{text-align:center;color:#ffd700;min-height:1.3em;margin-top:8px;font-size:.9em}
.note{color:#666;font-size:.8em;line-height:1.4;margin-bottom:10px}
.pill{display:inline-block;padding:2px 8px;border-radius:10px;font-size:.8em}
.pill.ok{background:#1a4a1a;color:#4f4}
.pill.off{background:#4a1a1a;color:#f44}
.track-state{text-align:center;font-size:1.3em;font-weight:bold;padding:8px 0 12px;letter-spacing:.05em}
.track-state.on{color:#4f4}.track-state.off{color:#f44}
.dbg-sec{color:#555;font-size:.72em;text-transform:uppercase;letter-spacing:.06em;padding:10px 0 3px;border-bottom:1px solid #1e1e3a;margin-bottom:2px}
.dbg-sec:first-child{padding-top:2px}
.dbg-row{display:grid;grid-template-columns:1.2em 1fr 1.2em 1fr 1.2em 1fr;gap:2px 6px;padding:4px 0;font-family:monospace;font-size:.88em;align-items:center}
.dbg-row .ax{color:#555;font-size:.8em}.dbg-row .av{color:#a0c4ff}
.dbg-kv{display:flex;justify-content:space-between;padding:4px 0;border-bottom:1px solid #1e1e3a;font-family:monospace;font-size:.9em}
.dbg-kv:last-child{border:none}.dk{color:#666}.dv{color:#a0c4ff}
.dv.hi{color:#f44}.dv.warn{color:#fa0}.dv.ok{color:#4f4}.dv.off{color:#f44}
.lim-row{display:flex;justify-content:space-between;padding:5px 0;font-size:.88em}
.lim-row span:first-child{color:#888}.lim-row span:last-child{color:#a0c4ff;font-family:monospace}
.hide{display:none}
</style>
</head>
<body>
<h2>&#x1F4E1; AutoSat</h2>
<div class="tabs">
  <button class="tab on"  onclick="tab('s',this)">Status</button>
  <button class="tab"     onclick="tab('e',this)">Elev.</button>
  <button class="tab"     onclick="tab('g',this)">GPS</button>
  <button class="tab"     onclick="tab('m',this)">Motor</button>
  <button class="tab"     onclick="tab('w',this)">WLAN</button>
  <button class="tab"     onclick="tab('d',this)">Debug</button>
</div>

<!-- STATUS -->
<div id="ts">
  <div class="box" id="statBox"><div class="center" style="color:#666;padding:20px">Lade...</div></div>
</div>
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

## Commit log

2026-06-26 Initial commit – AutoSat Prototyp v1
    Absolutes Azimut-Tracking per Kompass + Schrittmotor (TMC2209/NEMA17),
    Elevation per MG996R Servo. ESP32-C3 SuperMini, HMC5883L + MPU-6500.
    Webportal mit Kalibrierung, Live-Debug und Achsenauswahl.
    [Autosat-Elevation_Mount.stl, Nema17-Ground_Mount.stl]
2026-06-26 docs: README Repo-Struktur auf tatsächliche STL-Dateien aktualisiert
2026-06-26 docs: Bedienungsanleitung Web-Portal hinzugefügt und in README verlinkt
2026-06-27 docs: Schaltplan und Verdrahtung als Markdown hinzugefügt
2026-06-27 docs: Schleifring 6-polig in Schaltplan eingebaut (3 Adern Servo)
2026-06-27 docs: DC-DC Konverter 12V→5V in Teileliste und Schaltplan ergänzt
2026-06-27 docs: Schleifring-Details aus Schaltplan vereinfacht, Hinweis beim Servo
2026-06-29 firmware: Stufe 1+2 – Kompass aus Regelschleife, Gyro als primäre Heading-Quelle
    - motorRunning-Flag: gesetzt bei jedem Step, fällt 500ms nach letztem Step zurück
    - Vibrationserkennung: Stddev des Beschleunigungsbetrags über 10 Samples (>0.05g)
    - heading_yaw wird rein per Gyro-Integration geführt (kein Kompass im Loop)
    - compassHeading separat berechnet (tilt-kompensiert); 40-Sample-Stabilitätspuffer
    - Drift-Korrektur nur im gesicherten Stillstand: kein Motor, keine Vibration,
    Kompass-Stddev <2°, mindestens 5s Ruhe → 0.001×dt Korrekturrate
    - Startup: 30-Sample Kompass-Mittelwert (~3s) setzt initialen heading_yaw
    - Webportal: Kompass-Status + Heading im Debug-Tab; "Kompass neu e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
    [firmware.ino, webportal.h]
2026-07-02 firmware: Sanfte Bewegungen + Auto-Start beim Boot
    Bewegungsverhalten:
    - Azimut: updateAzimuth() unterscheidet Slew (>3° Fehler, stepMotorManual mit
    Anlauf/Auslauf-Rampe) von Live-Tracking (<=3°, schnelle kleine Korrekturen)
    - Servo: SERVO_STEP_MS_INIT (100ms/°) für Erst-Aktivierung, danach
    SERVO_STEP_MS_MANUAL (60ms/°) manuell / SERVO_STEP_MS_TRACKING (12ms/°) live
    - servoInitDone-Flag: sanfte Rampe bis Ziel erstmals erreicht, dann normale Speed
    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
2026-07-02 docs: Fritzing-Schaltplan autosat_v1.fzz hinzugefügt
    Grafischer Schaltplan der gesamten Verdrahtung als Fritzing-Datei.
    Ergänzt die bestehende Text-Dokumentation in docs/schaltplan.md.
    [autosat_v1.fzz]
